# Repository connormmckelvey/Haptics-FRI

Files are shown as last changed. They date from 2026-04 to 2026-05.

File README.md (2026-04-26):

# Haptics-FRI

Haptics-FRI is a wearable vibrotactile feedback system developed in the UT Austin Human Enabled Robotics Lab (HERL) for the Freshman Research Initiative (FRI) stream. The project explores how lightweight haptic cues can support motor learning and robotic teleoperation.

At a system level, a host computer sends motor activation commands to a USB dongle, the dongle relays those commands over ESP-NOW to a wearable band, and the band drives four vibration motors after remapping commands based on wrist orientation from an IMU.

## Project Goals

- Build a low-latency, wireless haptic communication loop
- Provide intuitive directional feedback using a 4-motor wearable band
- Keep feedback aligned to the user's physical orientation using IMU-based remapping
- Support rapid prototyping from both embedded firmware and host-side Python tools

## System Architecture

PC -> USB Serial -> Dongle (ESP32-C3) -> ESP-NOW -> Band (ESP32-C3 + MPU6050 + motor driver) -> 4 haptic motors

## Repository Structure

- firmware/: PlatformIO project for embedded firmware, protocol types, and test tooling
- firmware/src/dongle.cpp: Active dongle firmware (serial-to-ESP-NOW bridge)
- firmware/excluded_src/band.cpp: Band firmware (IMU-aware motor remapping and motor control)
- firmware/include/packet_types.h: Shared packet and IMU data structures
- firmware/tools/test_send_mtr_cmd.py: Python utility that sends random 4-byte motor packets
- masterpod_pcb_kicad/: KiCad design files and Gerber outputs for the wearable board
- software/Pose.py: MoveNet-based wrist tracking prototype for vision-driven haptic logic
- software/how_to_send_mtr_cmds.md: Serial packet protocol reference for host applications

## Hardware and Firmware

### Hardware

- 2x Seeed XIAO ESP32-C3 (dongle and band)
- MPU6050 IMU on band
- ULN2003A motor driver
- 4 haptic motors arranged as top/right/bottom/left
- External antenna recommended for reliable ESP-NOW range

### Firmware Responsibilities

- Dongle firmware:
	- Reads raw 4-byte motor commands from USB serial at 115200 baud
	- Forwards commands to the band via ESP-NOW
	- Tracks send success/failure on serial logs

- Band firmware:
	- Receives motor commands over ESP-NOW
	- Reads IMU orientation
	- Remaps motor indices to preserve directional meaning relative to wrist orientation
	- Drives motor output pins

### Packet Format

Each command is exactly 4 bytes:

- Byte 0: top motor
- Byte 1: right motor
- Byte 2: bottom motor
- Byte 3: left motor

Each byte is 0 (off) or 1 (on).

## Software Components

### Host Command Interface

- software/how_to_send_mtr_cmds.md documents the serial protocol
- firmware/tools/test_send_mtr_cmd.py provides a quick motor-command generator for validation

### Computer Vision Prototype

- software/Pose.py runs MoveNet (TensorFlow Hub) on webcam frames
- Detects wrist keypoints and demonstrates where haptic feedback logic can plug in
- Current feedback hook prints decisions; it is not yet wired to serial transmission

## Getting Started

### 1. Clone the repository

```bash
git clone https://github.com/connormmckelvey/Haptics-FRI
cd Haptics-FRI
```

### 2. Firmware setup (PlatformIO)

The firmware project is configured in firmware/platformio.ini for seeed_xiao_esp32c3.

From the firmware directory:

```bash
platformio run
platformio run --target upload
platformio device monitor -b 115200
```

Notes:

- The active source in firmware/src is the dongle firmware.
- Band firmware currently lives in firmware/excluded_src/band.cpp and is not in the default build path.
- Ensure dongle and band use the same ESP-NOW channel.
- Update the hardcoded band MAC address in firmware/src/dongle.cpp when changing hardware.

### 3. Python tooling setup

For motor command testing:

```bash
pip install pyserial
python firmware/tools/test_send_mtr_cmd.py
```

For vision prototype (software/Pose.py):

```bash
pip install opencv-python numpy tensorflow tensorflow-hub
python software/Pose.py
```

## Engineering Notes

- IMU calibration is performed at band startup; keep the device still during calibration.
- The serial command path uses raw bytes without framing, acknowledgements, or checksums.
- If packets stop midway, dongle firmware resets partial serial reads after a short timeout.

## Current Status and Known Gaps

- Root-level documentation is now expanded, but some subsystem docs are still in-progress.
- software/cv_docs.md is currently empty.
- Pose-to-haptics closed-loop integration is not complete yet.
- Band firmware is stored under excluded_src and may need project reconfiguration for direct builds.

## Suggested Next Milestones

1. Promote band firmware into an actively built PlatformIO target.
2. Add requirements files for reproducible Python environments.
3. Implement serial output from software/Pose.py into the 4-byte dongle protocol.
4. Add repeatable validation tests for motor mapping and IMU remapping behavior.

## Acknowledgment

This project was created in the UT Austin Freshman Research Initiative within the Human Enabled Robotics Lab (HERL), with the goal of combining embedded systems, wearable haptics, and human-robot interaction research.

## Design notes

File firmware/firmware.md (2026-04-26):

# Firmware Documentation

## Overview

The system consists of two firmware targets — the **dongle** and the **band**. The dongle plugs into a PC via USB and relays motor commands to the band over ESP-NOW. The band receives motor commands, remaps them based on wrist orientation using an IMU, and drives the haptic motors.

```
PC  --[USB Serial]-->  Dongle  --[ESP-NOW]-->  Band  --> Motors
```

---

## Hardware

Both devices are **Seeed XIAO ESP32-C3** boards. The band additionally uses:
- **MPU6050** IMU for wrist orientation (I2C on SDA=D4, SCL=D5)
- **ULN2003A** motor driver for 4 haptic motors

### Antenna
The XIAO ESP32-C3 has a u.FL connector for an external antenna. The external antenna must be connected for reliable range. Without it the board relies on the weak onboard PCB trace antenna.

---

## Dongle Firmware

### Responsibilities
- Receives 4-byte motor commands from the PC over USB serial
- Relays them to the band via ESP-NOW

### Configuration

| Macro | Default | Description |
|---|---|---|
| `DONGLE_DUMMY_MODE` | `1` | When set to `1`, ignores serial and sends cycling dummy motor updates. Set to `0` for production. |
| `DONGLE_DUMMY_PERIOD_MS` | `2000` | Interval between dummy sends in milliseconds |

To build for production, set `DONGLE_DUMMY_MODE` to `0` in the source or via a PlatformIO build flag:
```ini
build_flags = -DDONGLE_DUMMY_MODE=0
```

### Band MAC Address
The band's MAC address is hardcoded in the dongle firmware:
```cpp
uint8_t bandAddress[] = {0xE8, 0xF6, 0x0A, 0x17, 0x00, 0xC0};
```
If the band is replaced, update this to match the new board's MAC address. The band prints its MAC address over serial on boot.

### ESP-NOW Channel
Both devices must be on the same channel. Default is channel `6`. To change it, update the `initESPNOW()` call in `setup()` on both devices.

### Serial Output
On boot the dongle prints:
```
MAC Address: XX:XX:XX:XX:XX:XX
ESP-NOW init result: 1
```
An init result of `1` means success, `0` means ESP-NOW failed to initialize, `-1` means the band peer failed to register.

During operation it prints either `Successfully sent motor update` or `Failed to send motor update` after each ESP-NOW transmission.

---

## Band Firmware

### Responsibilities
- Receives motor commands from the dongle via ESP-NOW
- Reads wrist orientation from the MPU6050 IMU
- Remaps motor commands based on wrist orientation
- Drives 4 haptic motors via the ULN2003A

### Motor Layout
Motors are indexed clockwise starting from the top:

```
      0 (top)
3 (left)  1 (right)
      2 (bottom)
```

Motor GPIO pin assignments:
```cpp
uint8_t mtrPins[] = {2, 3, 4, 5}; // top, right, bottom, left
```

### Wrist Orientation Remapping
The IMU measures roll angle and quantizes it into 4 quadrants (0°, 90°, 180°, 270°). Incoming motor commands are offset by the current quadrant so that a command for the "top" motor always vibrates whichever motor is physically on top of the wrist at that moment.

### IMU Calibration
The IMU calibrates on every boot. The user should hold their wrist still for a few seconds after powering on until calibration completes. The band will print `Calibration complete` over serial when ready.

IMU I2C pins:
```cpp
#define SDA_PIN 4
#define SCL_PIN 5
```

### ESP-NOW Channel
Default is channel `6`. Must match the dongle. Update the `initESPNOW()` call in `setup()` to change it.

### Serial Output
On boot the band prints:
```
MAC Address: XX:XX:XX:XX:XX:XX
ESP-NOW init result: 1
MPU6050 connection successful
Calibrating IMU, hold still...
Calibration complete
```

During operation it prints the received motor states each time a packet arrives.

---

## Flashing

Both targets are built and flashed using PlatformIO. Open the correct project, select the appropriate environment, connect the device via USB, and run upload.

If the device does not appear on a COM port after reset, hold the **B** (boot) button, tap **R** (reset), then release **B** to enter bootloader mode before flashing.

---

## Troubleshooting

| Symptom | Likely Cause |
|---|---|
| Dongle prints `Failed to send motor update` | Band is powered off, out of range, or on a different channel |
| Band not receiving anything | Channel mismatch, or `esp_wifi_set_promiscuous` left enabled |
| Poor range | External antenna not connected to band or dongle |
| IMU not found | Wiring issue on SDA/SCL, or I2C address conflict |
| Motors not responding | GPIO pin assignments don't match physical wiring |

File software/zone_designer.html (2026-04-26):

# TACTUS // Zone Designer

v2.0

## Draw Tool

▭ Rectangle ⬡ Polygon (click) ✏ Freehand Draw

Click and drag to draw a rectangle zone.

## Snapping

Axis snap

Radius 14px

Points snap to horizontal/vertical alignment with existing edges, vertices, canvas edges and centre lines. Green diamond + guide line shows an active snap.

## Canvas Size

× Apply

Match your camera resolution for accurate zone placement.

## Zones 0

No zones yet.
Draw on the canvas to add zones.

RECT MODE ✓ Close Polygon

Simplify 6

⊕ SNAP Clear All x: — y: —

## Python Output

Copy

# Draw zones on the canvas
# to generate code here.

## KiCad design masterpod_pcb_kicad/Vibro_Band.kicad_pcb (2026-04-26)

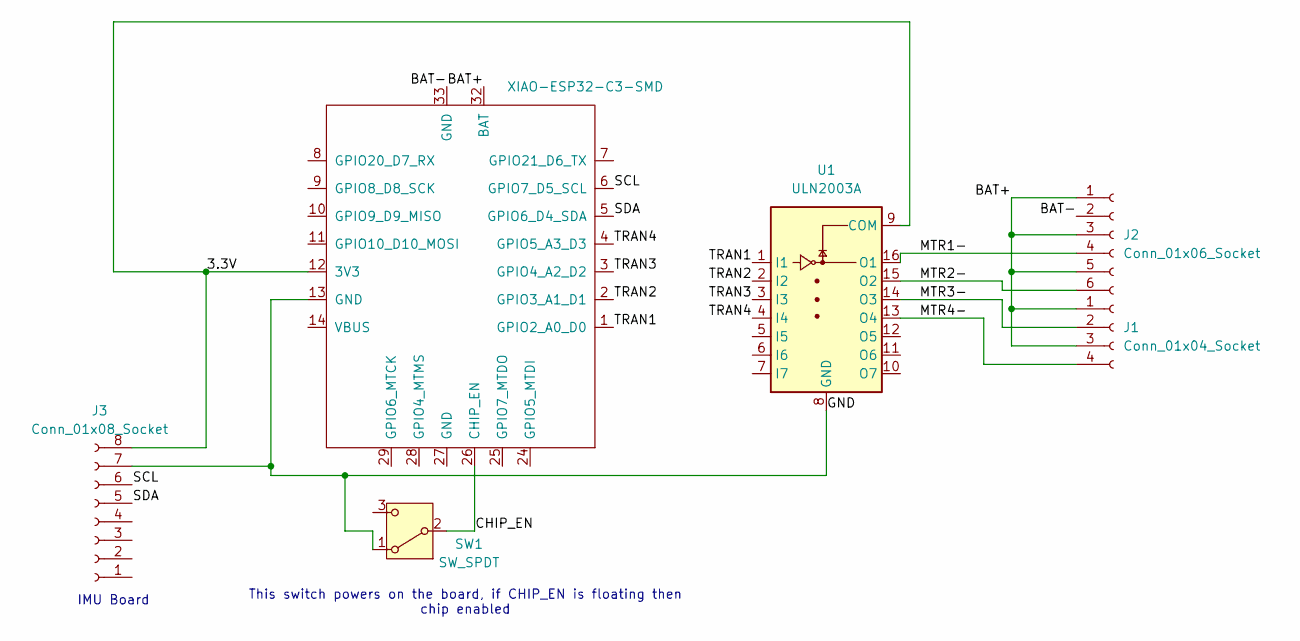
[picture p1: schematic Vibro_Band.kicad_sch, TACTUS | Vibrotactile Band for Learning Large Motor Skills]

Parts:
J1: Conn_01x04_Socket; PinSocket_1x04_P2.54mm_Horizontal
J2: Conn_01x06_Socket; PinSocket_1x06_P2.54mm_Horizontal
J3: Conn_01x08_Socket; PinSocket_1x08_P2.54mm_Horizontal
SW1: SW_SPDT; SW_Slide_SPDT_Angled_CK_OS102011MA1Q
U1: ULN2003A; DIP-16_W7.62mm
U3: XIAO-ESP32-C3-SMD

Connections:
/3.3V: J3.8, U1.9 (COM), U3.12 (3V3)
/BAT+: J1.1, J1.3, J2.1, J2.3, J2.5, U3.32 (BAT)
/BAT-: J2.2, U3.33 (GND)
/CHIP_EN: SW1.2 (B), U3.26 (CHIP_EN)
/GND: J3.7, SW1.1 (A), U1.8 (GND), U3.13 (GND)
/MTR1-: J2.4, U1.16 (O1)
/MTR2-: J2.6, U1.15 (O2)
/MTR3-: J1.2, U1.14 (O3)
/MTR4-: J1.4, U1.13 (O4)
/SCL: J3.6, U3.6 (GPIO7_D5_SCL)
/SDA: J3.5, U3.5 (GPIO6_D4_SDA)
/TRAN1: U1.1 (I1), U3.1 (GPIO2_A0_D0)
/TRAN2: U1.2 (I2), U3.2 (GPIO3_A1_D1)
/TRAN3: U1.3 (I3), U3.3 (GPIO4_A2_D2)
/TRAN4: U1.4 (I4), U3.4 (GPIO5_A3_D3)

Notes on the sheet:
This switch powers on the board, if CHIP_EN is floating then chip enabled
IMU Board

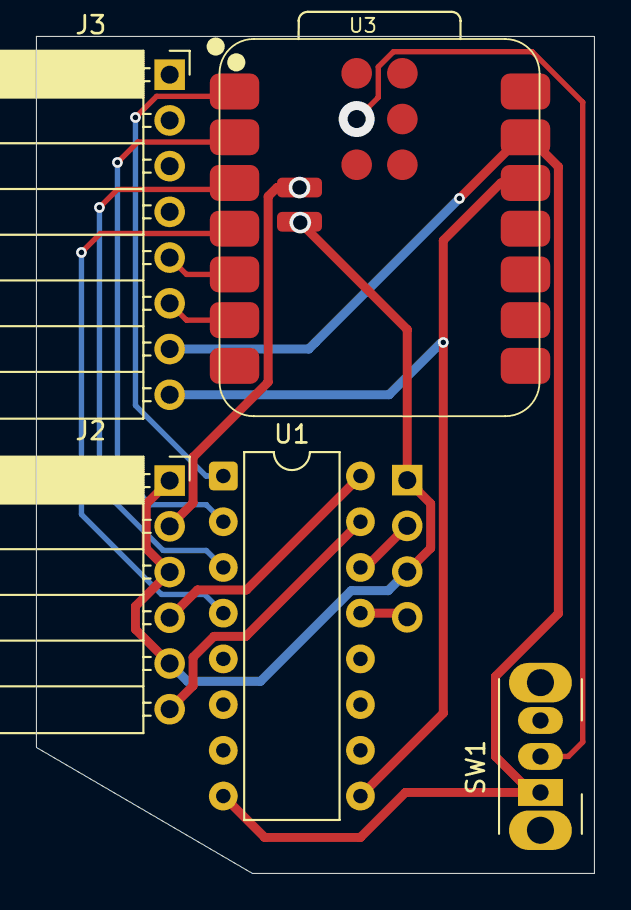
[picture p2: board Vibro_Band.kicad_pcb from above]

Board: 2 copper layers, 31.0 x 46.5 mm, 6 parts (1 on the bottom side), 15 nets.

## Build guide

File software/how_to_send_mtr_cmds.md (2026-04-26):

# Dongle Serial Protocol

## Overview

The dongle accepts raw bytes over USB serial and relays them to the wearable band via ESP-NOW. There is no framing, no handshake, and no acknowledgement.

## Connection Settings

| Parameter | Value |
|---|---|
| Baud rate | 115200 |

## Packet Format

Every motor command is exactly **4 bytes**, one byte per motor:

| Byte | Motor | Position |
|---|---|---|
| 0 | Motor 0 | Top |
| 1 | Motor 1 | Right |
| 2 | Motor 2 | Bottom |
| 3 | Motor 3 | Left |

Each byte is either `0x00` (off) or `0x01` (on).

## Rules

- Send all 4 bytes together — do not insert delays between bytes. The dongle will reset its buffer if a partial packet stalls for more than 10ms.
- There is no acknowledgement back from the dongle.
- There is no start byte or header — do not send anything before the 4 motor bytes.
- Do not send newline characters or any other framing.

## Examples

Vibrate top motor only:
```
0x01 0x00 0x00 0x00
```

Vibrate right motor only:
```
0x00 0x01 0x00 0x00
```

Vibrate all motors:
```
0x01 0x01 0x01 0x01
```

All motors off:
```
0x00 0x00 0x00 0x00
```

## Python Example

```python
import serial

ser = serial.Serial('COM3', 115200)  # replace COM3 with your port

# Vibrate top motor only
ser.write(bytes([1, 0, 0, 0]))

# Vibrate right motor only
ser.write(bytes([0, 1, 0, 0]))

# All motors off
ser.write(bytes([0, 0, 0, 0]))
```

## Notes

- The band automatically remaps motor commands based on wrist orientation using the onboard IMU. A command for the "top" motor will always vibrate whichever motor is physically on top of the wrist at that moment.
- If the band is out of range or powered off, the dongle will silently drop the packet.

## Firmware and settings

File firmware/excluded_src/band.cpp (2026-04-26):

#include <Arduino.h>
#include <esp_now.h>
#include <WiFi.h>
#include <esp_wifi.h>
#include "packet_types.h"
#include "MPU6050.h"

///////////////
// GLOBALS
///////////////
#define IMU_SAMPLE_INTERVAL 200 // in milliseconds
#define IMU_CALIBRATION_INTERVAL 1000000 // in milliseconds
#define SCL_PIN 7
#define SDA_PIN 6
// Set to 1 to locally drive motors from IMU test code in loop().
// Default 0 keeps production behavior: ESP-NOW commands -> remap -> motors.
#define BAND_IMU_TEST_MODE 0

MPU6050 imu;
esp_now_peer_info_t peerInfo;
//uint8_t laptopDongleAddress[] = {0xE8, 0xF6, 0x0A, 0x16, 0xFF, 0x94}; // laptop dongle MAC address
uint8_t numMotors;
uint8_t motorpins[4];
uint16_t successful_sends = 0;
uint16_t failed_sends = 0;
unsigned long last_imu_get_time = 0;
unsigned long last_imu_calibration_time = 0;
int initResult;


///////////////
// FUNCTION DECLARATIONS
///////////////
int initMotors(uint8_t motorpins[]);
int updateMotorStates(motor_update_t motor_update);
float getWristPitchDegrees();
uint8_t getWristMotorOffset();
motor_update_t remapMotors(motor_update_t received);
int initIMU();
void calibrateIMU();
imu_data_t get_imu_data();
int initESPNOW(uint8_t channel);
void onDataRecv(const uint8_t * mac, const uint8_t *incomingData, int len);
void displayMACAddress();
void displayChannel();


///////////////
// MAIN 
///////////////
void setup() {
  last_imu_get_time = 0;
  Serial.begin(115200);
  displayMACAddress();
  initResult = initESPNOW(6);
  if (initIMU()) {
    calibrateIMU();
  }  
  uint8_t mtrPins[] = {2,3,4,5};
  initMotors(mtrPins);
}

void loop() {
#if BAND_IMU_TEST_MODE
  // IMU test mode: keep requesting the top motor, then remap it using the
  // current wrist quadrant so we can verify orientation tracking.
  if (millis() - last_imu_get_time >= IMU_SAMPLE_INTERVAL) {
    last_imu_get_time = millis();

    motor_update_t topMotorCommand{};
    topMotorCommand.motor_states[0] = HIGH;

    motor_update_t remapped = remapMotors(topMotorCommand);
    updateMotorStates(remapped);

    Serial.print("IMU pitch: ");
    Serial.println(getWristPitchDegrees());
    Serial.print("Motor offset: ");
    Serial.println(getWristMotorOffset());
    Serial.print("Remapped motor states: ");
    for (int i = 0; i < 4; i++) {
      Serial.print(remapped.motor_states[i]);
      Serial.print(" ");
    }
    Serial.println();
  }
#endif
}

///////////////
// FUNCTION DEFINITIONS
///////////////

// motor control
// initalize numMotors, motorpins, pinMode, and set all motors to off
int initMotors(uint8_t mtrpins[]) {
  for (int i = 0; i < 4; i++) {
    motorpins[i] = mtrpins[i];
    pinMode(motorpins[i], OUTPUT);
    digitalWrite(motorpins[i], LOW); // start with motors off
  }
  return 1;
}

//update motor states based on motor_update struct received through ESPNOW
int updateMotorStates(motor_update_t motor_update) {
  for (int i = 0; i < 4; i++) {
    digitalWrite(motorpins[i], motor_update.motor_states[i]);
  }
  return 1;
}

// Returns the wrist pitch angle in degrees, normalized to 0-360.
float getWristPitchDegrees() {
  imu_data_t data = get_imu_data();
  
  // Convert accelerometer to pitch angle (-180 to 180 degrees).
  // This uses rotation around the IMU Y axis.
  float pitch = atan2(-data.ax, data.az) * 180.0 / M_PI;
  
  // Shift to 0-360
  if (pitch < 0) pitch += 360.0;

  return pitch;
}

// Map the measured pitch bands to a single motor offset.
// These thresholds are tuned to the angles observed on the bench and avoid
// splitting the output across two motors.
uint8_t getWristMotorOffset() {
  float pitch = getWristPitchDegrees();

  if (pitch >= 337.5 || pitch < 20.0) {
    return 0; // top
  }
  if (pitch < 155.0) {
    return 1; // right
  }
  if (pitch < 292.5) {
    return 2; // bottom
  }
  return 3; // left
}

// Remap motor update based on wrist rotation.
// The band only has four motor outputs, so this uses measured pitch bands to
// select a single physical motor per orientation.
motor_update_t remapMotors(motor_update_t received) {
  motor_update_t remapped{};

  uint8_t offset = getWristMotorOffset();

  for (int i = 0; i < 4; i++) {
    remapped.motor_states[(i + offset) % 4] = received.motor_states[i];
  }
  return remapped;
}


int initIMU() {
  Wire.begin(SDA_PIN, SCL_PIN);
  imu.initialize();
  
  if (!imu.testConnection()) {
    Serial.println("MPU6050 connection failed");
    return 0;
  }
  Serial.println("MPU6050 connection successful");
  return 1;
}

void calibrateIMU() {    
  Serial.println("Calibrating IMU, hold still...");
  imu.setXAccelOffset(0); imu.setYAccelOffset(0); imu.setZAccelOffset(0);
  imu.setXGyroOffset(0);  imu.setYGyroOffset(0);  imu.setZGyroOffset(0);
  imu.CalibrateAccel(6);
  imu.CalibrateGyro(6);
  Serial.println("Calibration complete");
}

imu_data_t get_imu_data() {
  imu_data_t data;
  imu.getMotion6(&data.ax, &data.ay, &data.az, &data.gx, &data.gy, &data.gz);
  return data;
}


int initESPNOW(uint8_t channel = 1) {
  WiFi.mode(WIFI_STA);

  esp_wifi_set_promiscuous(true);
  esp_wifi_set_channel(channel, WIFI_SECOND_CHAN_NONE);
  esp_wifi_set_promiscuous(false); // was being called twice, also should be false after setting channel

  if (esp_now_init() != ESP_OK) { return 0; }

  esp_now_register_recv_cb(onDataRecv);

  return 1;
}

void onDataRecv(const uint8_t * mac, const uint8_t *incomingData, int len) {
  motor_update_t received;
  memcpy(&received, incomingData, sizeof(motor_update_t));
  motor_update_t remapped = remapMotors(received);
  updateMotorStates(remapped);

  Serial.println("Updated Motor States:");
  for (int i = 0; i < 4; i++) {
    Serial.print(remapped.motor_states[i]);
    Serial.print(" ");
  }
  Serial.println();
}

//assumes serial.begin() has already been called
//assumes wifi.mode is set to WIFI_STA
void displayMACAddress(){
  Serial.print("MAC Address: ");
  Serial.println(WiFi.macAddress());
}

void displayChannel(){
  uint8_t primaryChan;
  wifi_second_chan_t secondChan;
  esp_wifi_get_channel(&primaryChan, &secondChan);
  Serial.print("Actual channel: ");
  Serial.println(primaryChan);
}

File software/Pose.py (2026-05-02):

import cv2
import numpy as np
import tensorflow as tf
import tensorflow_hub as hub
import math
import serial

# Config
MODEL_URL = "https://tfhub.dev/google/movenet/singlepose/lightning/4"
INPUT_SIZE = 192
CONF_THRESHOLD = 0.15

LEFT_SHOULDER, LEFT_ELBOW, LEFT_WRIST = 5, 7, 9
RIGHT_SHOULDER, RIGHT_ELBOW, RIGHT_WRIST = 6, 8, 10

STRAIGHT_ARM_THRESHOLD = 160

SERIAL_PORT = "COM5"
BAUD_RATE = 115200

# Motor packet [top, right, bottom, left]
MOTORS_OFF = bytes([0, 0, 0, 0])

# ZONES
ZONES = [
    {  # Zone 1 - rect
        "type": "rect",
        "x":  0.3025,  "y":  0.2952,
        "x2": 0.7328, "y2": 0.7297,
    },
]

# True is zone based detection and false is angle mode
USE_ZONE_MODE = True

# Zone helpers
def _point_in_zone(nx, ny, zone):
    if zone["type"] == "rect":
        return zone["x"] <= nx <= zone["x2"] and zone["y"] <= ny <= zone["y2"]
    # Polygon ray-casting algorithm
    pts = zone["pts"]
    inside = False
    j = len(pts) - 1
    for i in range(len(pts)):
        xi, yi = pts[i]
        xj, yj = pts[j]
        if ((yi > ny) != (yj > ny)) and (nx < (xj - xi) * (ny - yi) / (yj - yi) + xi):
            inside = not inside
        j = i
    return inside

def _zone_bounding_box(zone):
    if zone["type"] == "rect":
        return zone["x"], zone["y"], zone["x2"], zone["y2"]
    xs = [p[0] for p in zone["pts"]]
    ys = [p[1] for p in zone["pts"]]
    return min(xs), min(ys), max(xs), max(ys)

# Directional exit detection
def get_exit_directions(wx_px, wy_px, frame_w, frame_h):
    nx = wx_px / frame_w
    ny = wy_px / frame_h

    # If the wrist is inside any zone no haptic needed
    if any(_point_in_zone(nx, ny, z) for z in ZONES):
        return []

    # Wrist is outside all zones, determine exit direction from combined bbox
    all_x1 = min(_zone_bounding_box(z)[0] for z in ZONES)
    all_y1 = min(_zone_bounding_box(z)[1] for z in ZONES)
    all_x2 = max(_zone_bounding_box(z)[2] for z in ZONES)
    all_y2 = max(_zone_bounding_box(z)[3] for z in ZONES)

    directions = []
    if ny < all_y1: directions.append("top")
    if ny > all_y2: directions.append("bottom")
    if nx < all_x1: directions.append("left")
    if nx > all_x2: directions.append("right")
    return directions

def directions_to_motor_packet(directions):
    top    = 1 if "top"    in directions else 0
    right  = 1 if "right"  in directions else 0
    bottom = 1 if "bottom" in directions else 0
    left   = 1 if "left"   in directions else 0
    return bytes([top, right, bottom, left])

def draw_zone(frame, frame_w, frame_h, directions):
    for zone in ZONES:
        if zone["type"] == "rect":
            x1 = int(zone["x"]  * frame_w)
            y1 = int(zone["y"]  * frame_h)
            x2 = int(zone["x2"] * frame_w)
            y2 = int(zone["y2"] * frame_h)
            cv2.rectangle(frame, (x1, y1), (x2, y2), (0, 200, 200), 1)
            t = 3
            if "top"    in directions: cv2.line(frame, (x1, y1), (x2, y1), (0, 0, 255), t)
            if "bottom" in directions: cv2.line(frame, (x1, y2), (x2, y2), (0, 0, 255), t)
            if "left"   in directions: cv2.line(frame, (x1, y1), (x1, y2), (0, 0, 255), t)
            if "right"  in directions: cv2.line(frame, (x2, y1), (x2, y2), (0, 0, 255), t)
        else:
            # Polygon zone
            pts_px = np.array(
                [(int(p[0] * frame_w), int(p[1] * frame_h)) for p in zone["pts"]],
                dtype=np.int32
            )
            color = (0, 0, 255) if directions else (0, 200, 200)
            cv2.polylines(frame, [pts_px], isClosed=True, color=color, thickness=2)

# Serial helpers
def open_serial():
    try:
        ser = serial.Serial(SERIAL_PORT, BAUD_RATE, timeout=0)
        print(f"[Serial] Connected on {SERIAL_PORT} @ {BAUD_RATE} baud.")
        return ser
    except serial.SerialException as e:
        print(f"[Serial] WARNING - {e}. Running without haptics.")
        return None

def send_motor_packet(ser, packet):
    if ser is None:
        return
    try:
        ser.write(packet)
    except serial.SerialException as e:
        print(f"[Serial] Write error: {e}")

# MoveNet
module = hub.load(MODEL_URL)
model = module.signatures["serving_default"]

def run_movenet(frame_bgr):
    frame_rgb = cv2.cvtColor(frame_bgr, cv2.COLOR_BGR2RGB)
    image = tf.expand_dims(frame_rgb, axis=0)
    image = tf.image.resize_with_pad(image, INPUT_SIZE, INPUT_SIZE)
    image = tf.cast(image, dtype=tf.int32)
    return model(image)["output_0"].numpy()

def get_keypoint(keypoints, w, h, index):
    y_norm, x_norm, score = keypoints[0, 0, index]
    return int(x_norm * w), int(y_norm * h), float(score)

def calculate_arm_angle(shoulder, elbow, wrist):
    if shoulder[2] < CONF_THRESHOLD or elbow[2] < CONF_THRESHOLD or wrist[2] < CONF_THRESHOLD:
        return None
    ba = (shoulder[0] - elbow[0], shoulder[1] - elbow[1])
    bc = (wrist[0] - elbow[0], wrist[1] - elbow[1])
    dot = ba[0]*bc[0] + ba[1]*bc[1]
    mag_ba = math.sqrt(ba[0]**2 + ba[1]**2)
    mag_bc = math.sqrt(bc[0]**2 + bc[1]**2)
    if mag_ba == 0 or mag_bc == 0:
        return None
    return math.degrees(math.acos(max(-1, min(1, dot / (mag_ba * mag_bc)))))
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

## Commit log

2026-04-02 set up structure and coded out espnow protocol and datastructure. missing IMU implementation
    [band.cpp, dongle.cpp, main.cpp]
2026-04-07 added kicad files
    [Vibro_Band.kicad_pcb, Vibro_Band.kicad_sch]
2026-04-08 band working to test motor with new ULN2003a Driver
2026-04-09 v1 working esp_now with sending dummy motor commands, pins switching correctly. only missing IMU implementation
    [band.cpp, dongle.cpp]
2026-04-09 updates to packet struct and implemented imu rotation NOT TESTED
2026-04-11 finished pcb?
    [Vibro_Band.kicad_pcb, Vibro_Band.kicad_sch]
2026-04-13 pcb updates
2026-04-13 new pcb updates
2026-04-18 updates to kicad
    [Vibro_Band-B_Cu.gbr, Vibro_Band-B_Mask.gbr, Vibro_Band-B_Paste.gbr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]
2026-04-19 working IMU feedback!
    [Vibro_Band-B_Cu.gbr, Vibro_Band-B_Mask.gbr, Vibro_Band-B_Paste.gbr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]
2026-04-26 updates to readme and cleanup of unsed functions
    [Vibro_Band.kicad_sch]
2026-04-27 mirrored camera issue fix
    [Pose.py]
